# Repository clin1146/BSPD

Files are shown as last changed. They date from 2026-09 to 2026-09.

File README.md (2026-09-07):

# Brake System Plausibility Device (BSPD)

**Manchester Stinger Motorsports** · Rev V4.0

The BSPD is a **non-programmable safety circuit**, implemented entirely in discrete
logic with **no microcontroller anywhere in the fault-detection or shutdown path**.
It continuously monitors the throttle position sensor (TPS) and brake pressure
sensor (BPS) and cuts power to the vehicle if either reports an implausible
condition.

---

## Fault conditions

### 1. Simultaneous brake and throttle
If the BPS indicates the brakes are applied while the TPS reads **more than 25 %
above idle position**, and both conditions persist continuously for **500 ms**, the
circuit cuts power to the vehicle.

### 2. Sensor signal out of range
If either the TPS or BPS signal falls outside the expected **0.5 V – 4.5 V** range
for **500 ms** — indicating a wiring fault, sensor failure, or an open or short
circuit — the circuit cuts power.

---

## Reset behaviour

Once the fault condition is no longer true, a 10-second timer starts. If no fault
recurs within that 10-second window, power resets automatically. If a fault recurs
during the window, the timer restarts, so power stays cut until a full 10 seconds
passes with no fault present.

---

## Functional block diagram

![BSPD functional block diagram: the BPS and TPS sensor signals feed an AND stage
(simultaneous brake and throttle); its output is OR'd with the SCS signal, which
flags either sensor leaving the 0.5–4.5 V range. The combined fault passes through
a 500 ms RC delay that latches Power Off, and drives an inverter into a 555-based
10 s timer that restores Power On once the fault has been clear for the full
window.](docs/system-block-diagram.png)

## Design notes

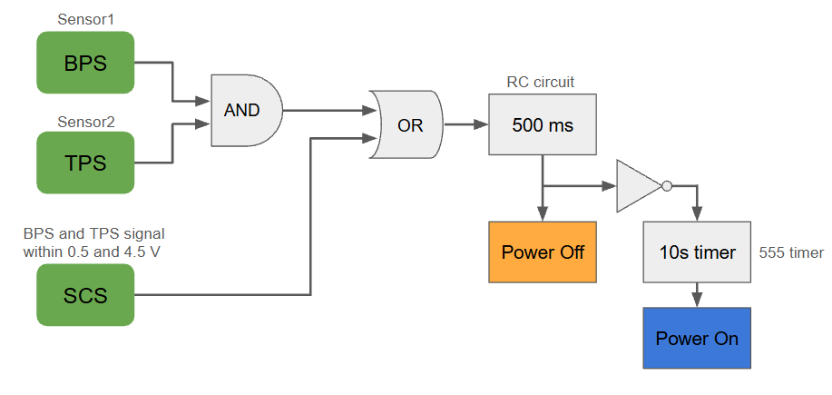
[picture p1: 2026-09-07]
docs/system-block-diagram.png

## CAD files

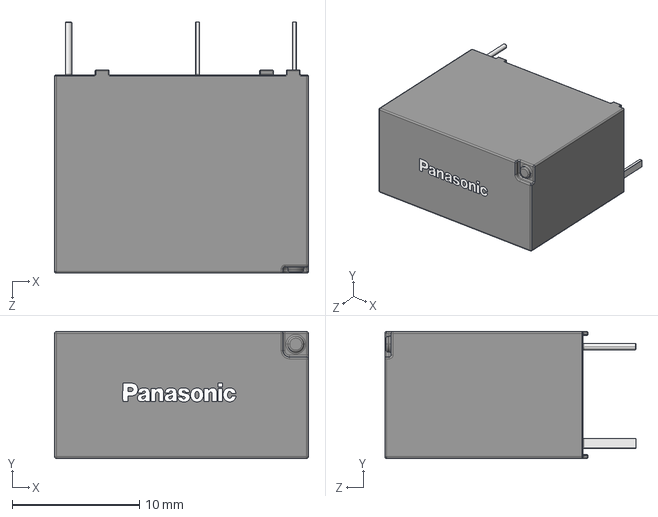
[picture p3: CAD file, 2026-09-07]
BSPD PCB/footprints/3D/ALQ3F12.stp
20.0 x 10.0 x 19.8 mm
ALQ305
Panasonic_Logo_5mm

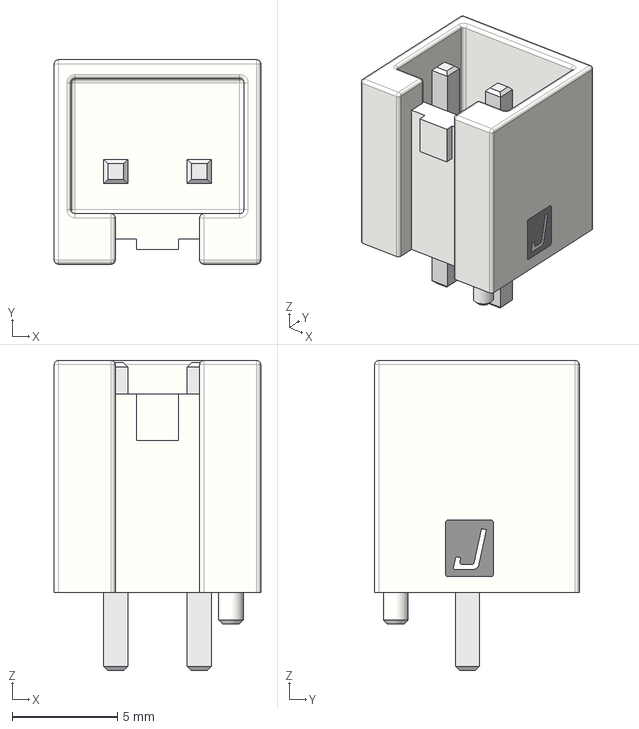
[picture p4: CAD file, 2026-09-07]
BSPD PCB/footprints/3D/B2P-VH-FB-B_LF__SN_.stp
9.80 x 9.70 x 14.7 mm

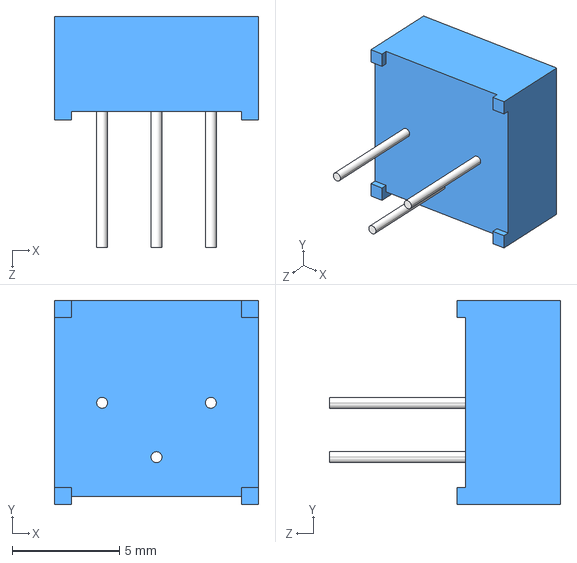
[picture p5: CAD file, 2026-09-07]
BSPD PCB/footprints/3D/3386P-1-500LF.stp
9.53 x 9.53 x 10.8 mm

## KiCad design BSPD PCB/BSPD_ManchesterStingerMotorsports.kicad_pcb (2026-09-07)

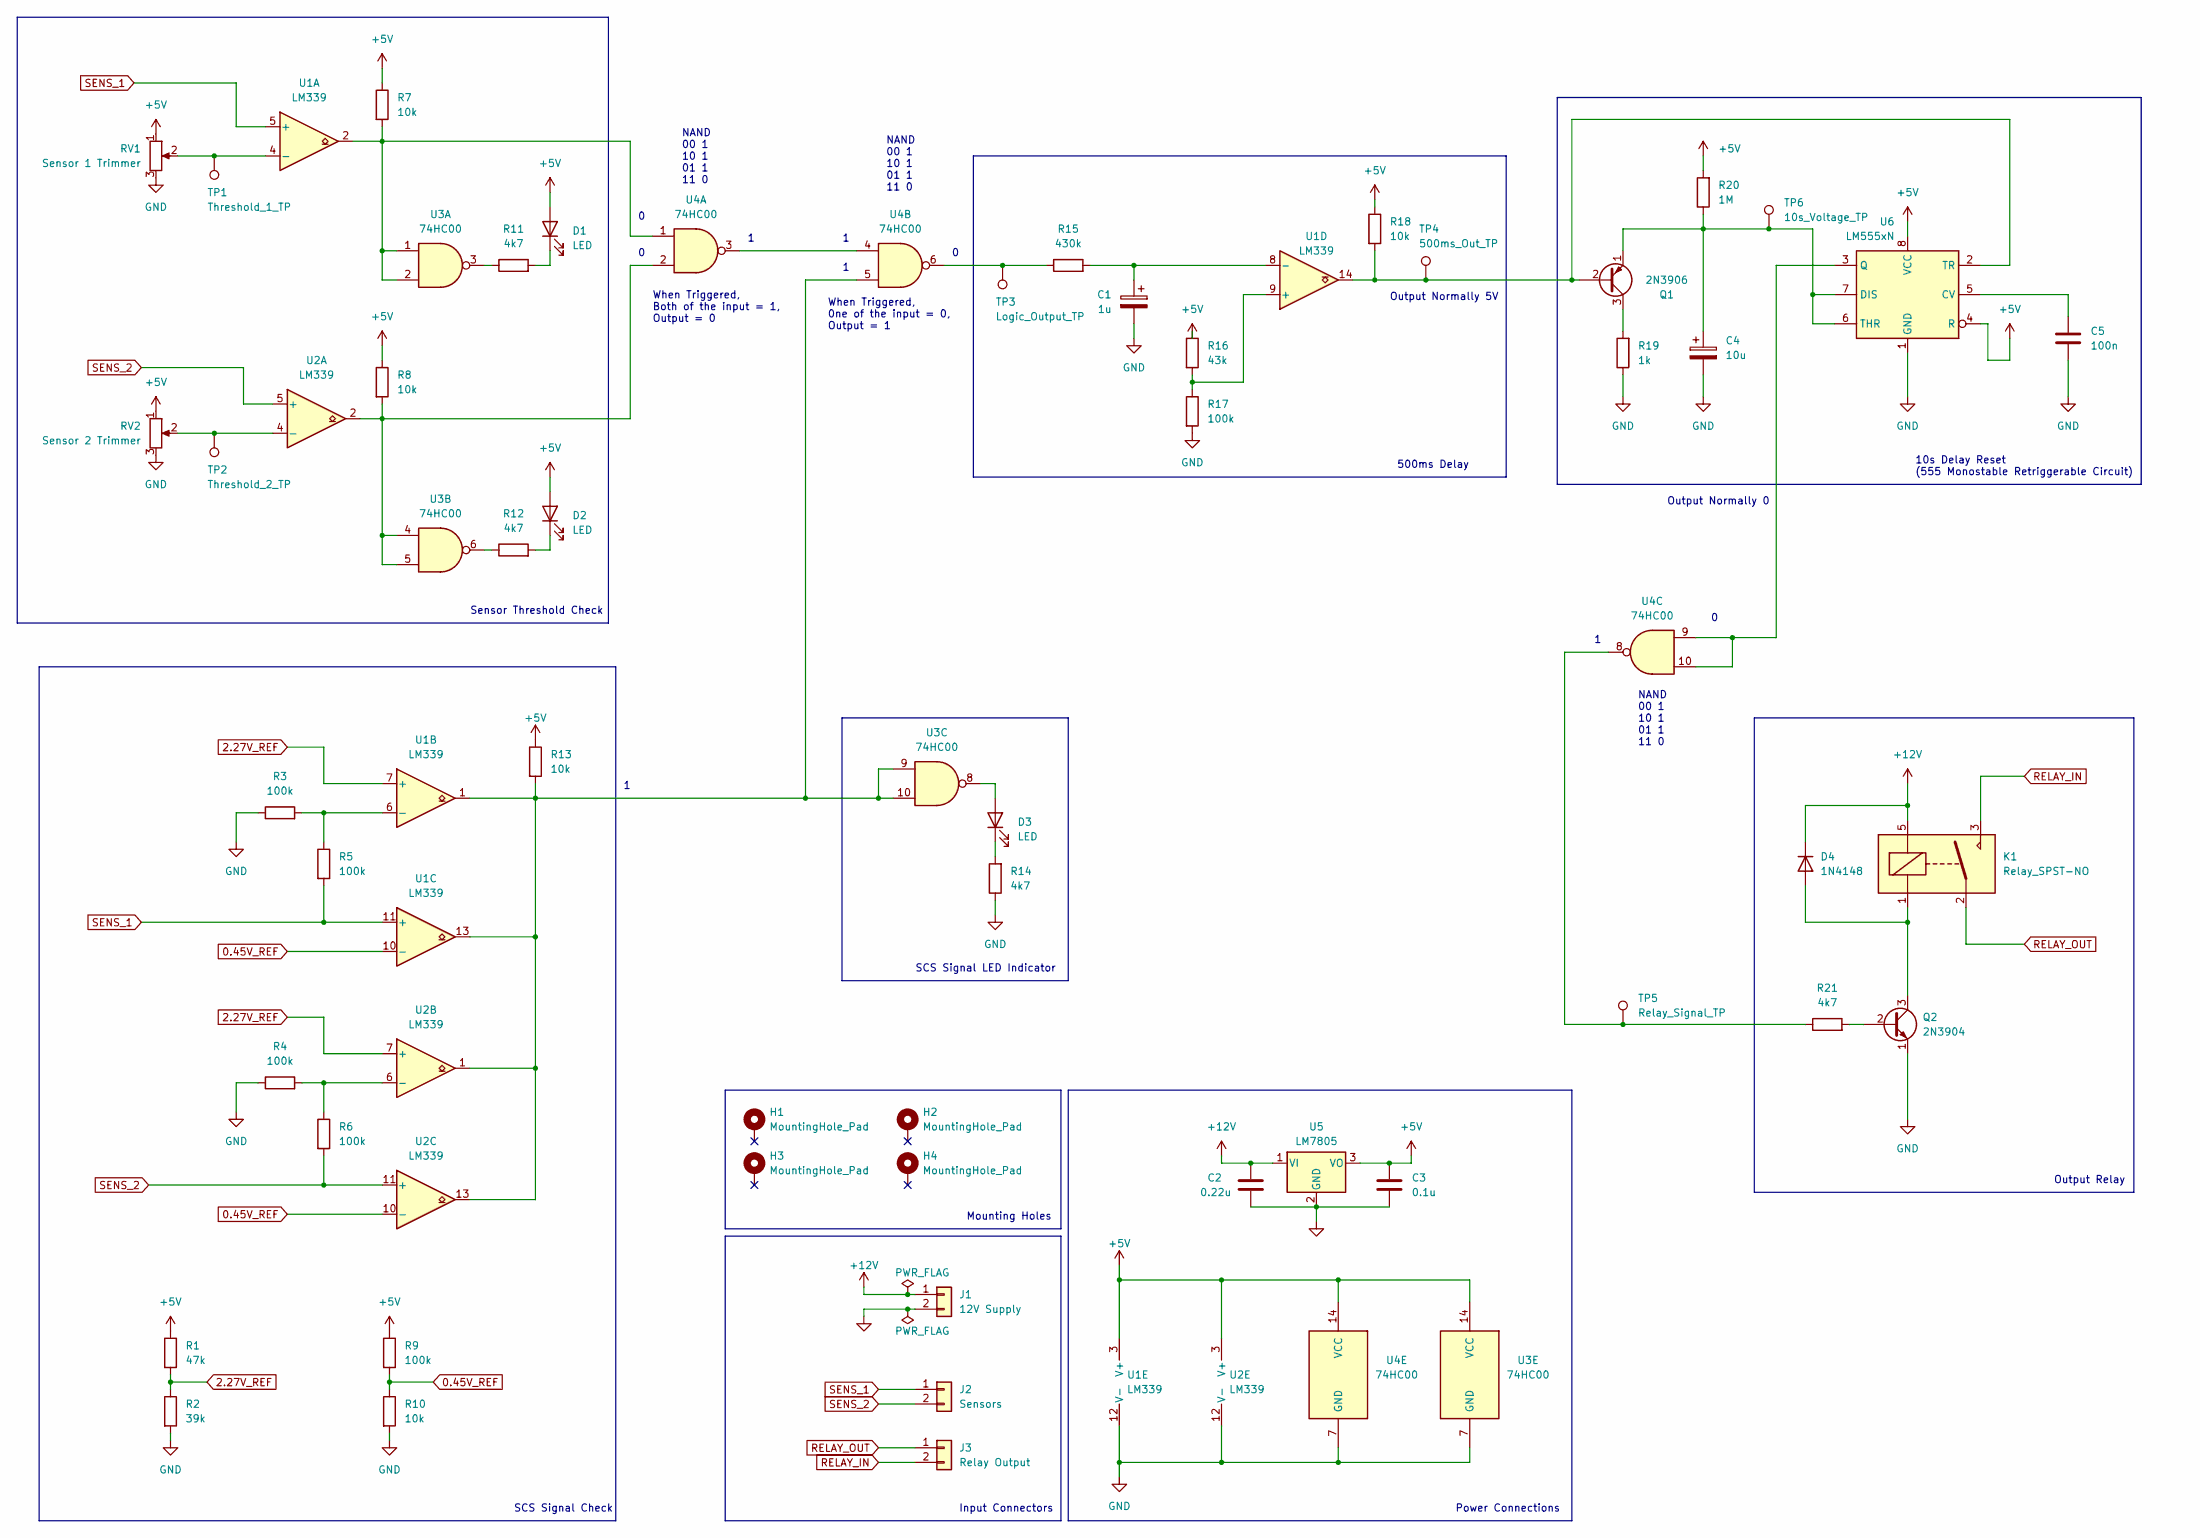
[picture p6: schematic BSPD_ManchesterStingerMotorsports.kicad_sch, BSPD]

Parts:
C1: 1u; CP_Radial_D5.0mm_P2.00mm
C2: 0.22u; C_Disc_D8.0mm_W2.5mm_P5.00mm
C3: 0.1u; C_Disc_D8.0mm_W2.5mm_P5.00mm
C4: 10u; CP_Radial_D5.0mm_P2.00mm
C5: 100n; C_Disc_D8.0mm_W2.5mm_P5.00mm
D1, D2, D3: LED; LED_D3.0mm
D4: 1N4148; D_DO-35_SOD27_P7.62mm_Horizontal
H1, H2, H3, H4: MountingHole_Pad; MountingHole_3.2mm_M3_DIN965_Pad
J1: 12V Supply; JST_VH_B2P-VH-FB-B_1x02_P3.96mm_Vertical
J2: Sensors; TerminalBlock_Phoenix_MPT-0,5-2-2.54_1x02_P2.54mm_Horizontal
J3: Relay Output; JST_VH_B2P-VH-FB-B_1x02_P3.96mm_Vertical
K1: Relay_SPST-NO; ALQ305
Q1: 2N3906; TO-92L_Wide
Q2: 2N3904; TO-92L_Wide
R1: 47k; R_Axial_DIN0207_L6.3mm_D2.5mm_P10.16mm_Horizontal
R2: 39k; R_Axial_DIN0207_L6.3mm_D2.5mm_P10.16mm_Horizontal
R3, R4, R5, R6, R9, R17: 100k; R_Axial_DIN0207_L6.3mm_D2.5mm_P10.16mm_Horizontal
R7, R8, R10, R13, R18: 10k; R_Axial_DIN0207_L6.3mm_D2.5mm_P10.16mm_Horizontal
R11, R12, R14, R21: 4k7; R_Axial_DIN0207_L6.3mm_D2.5mm_P10.16mm_Horizontal
R15: 430k; R_Axial_DIN0207_L6.3mm_D2.5mm_P10.16mm_Horizontal
R16: 43k; R_Axial_DIN0207_L6.3mm_D2.5mm_P10.16mm_Horizontal
R19: 1k; R_Axial_DIN0207_L6.3mm_D2.5mm_P10.16mm_Horizontal
R20: 1M; R_Axial_DIN0207_L6.3mm_D2.5mm_P10.16mm_Horizontal
RV1: Sensor 1 Trimmer; Potentiometer_Bourns_3386P_Vertical
RV2: Sensor 2 Trimmer; Potentiometer_Bourns_3386P_Vertical
TP1: Threshold_1_TP; TestPoint_Loop_D1.80mm_Drill1.0mm_Beaded
TP2: Threshold_2_TP; TestPoint_Loop_D1.80mm_Drill1.0mm_Beaded
TP3: Logic_Output_TP; TestPoint_Loop_D1.80mm_Drill1.0mm_Beaded
TP4: 500ms_Out_TP; TestPoint_Loop_D1.80mm_Drill1.0mm_Beaded
TP5: Relay_Signal_TP; TestPoint_Loop_D1.80mm_Drill1.0mm_Beaded
TP6: 10s_Voltage_TP; TestPoint_Loop_D1.80mm_Drill1.0mm_Beaded
U1, U2: LM339; DIP-14_W7.62mm
U3, U4: 74HC00; DIP-14_W7.62mm
U5: LM7805; TO-220-3_Horizontal_TabDown
U6: LM555xN; DIP-8_W7.62mm

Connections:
0.45V_REF: R9.2, R10.1, U1.10 (-), U2.10 (-)
2.27V_REF: R1.2, R2.1, U1.7 (+), U2.7 (+)
+5V: C3.1, D1.2 (A), D2.2 (A), R1.1, R7.1, R8.1, R9.1, R13.1, R16.1, R18.1, R20.2, RV1.1, RV2.1, U1.3 (V+), U2.3 (V+), U3.14 (VCC), U4.14 (VCC), U5.3 (VO), U6.4 (R), U6.8 (VCC)
+12V: C2.1, D4.1 (K), J1.1, K1.5, U5.1 (VI)
GND: C1.2, C2.2, C3.2, C4.2, C5.2, J1.2, Q2.1 (E), R2.2, R3.1, R4.1, R10.2, R14.1, R17.2, R19.1, RV1.3, RV2.3, U1.12 (V-), U2.12 (V-), U3.7 (GND), U4.7 (GND), U5.2 (GND), U6.1 (GND)
unnamed: D1.1 (K), R11.2
unnamed: D2.1 (K), R12.2
unnamed: D3.2 (A), U3.8
unnamed: D3.1 (K), R14.2
unnamed: D4.2 (A), K1.1, Q2.3 (C)
unnamed: Q1.2 (B), R18.2, TP4.1, U1.14, U6.2 (TR)
unnamed: Q1.3 (C), R19.2
unnamed: C4.1, Q1.1 (E), R20.1, TP6.1, U6.6 (THR), U6.7 (DIS)
unnamed: Q2.2 (B), R21.2
unnamed: R7.2, U1.2, U3.1, U3.2, U4.1
unnamed: R8.2, U2.2, U3.4, U3.5, U4.2
unnamed: R11.1, U3.3
unnamed: R12.1, U3.6
unnamed: R13.2, U1.1, U1.13, U2.1, U2.13, U3.9, U3.10, U4.5
unnamed: R15.1, TP3.1, U4.6
unnamed: R21.1, TP5.1, U4.8
unnamed: RV1.2, TP1.1, U1.4 (-)
unnamed: R3.2, R5.1, U1.6 (-)
unnamed: R16.2, R17.1, U1.9 (+)
unnamed: C1.1, R15.2, U1.8 (-)
unnamed: RV2.2, TP2.1, U2.4 (-)
unnamed: R4.2, R6.1, U2.6 (-)
unnamed: U4.3, U4.4
unnamed: C5.1, U6.5 (CV)
unnamed: U4.9, U4.10, U6.3 (Q)
RELAY_IN: J3.2, K1.3
RELAY_OUT: J3.1, K1.2
SENS_1: J2.1, R5.2, U1.5 (+), U1.11 (+)
SENS_2: J2.2, R6.2, U2.5 (+), U2.11 (+)

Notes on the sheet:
SCS Signal Check
When Triggered, Both of the input = 1, Output = 0
500ms Delay
Mounting Holes
Output Relay
SCS Signal LED Indicator
Power Connections
NAND 00 1 10 1 01 1 11 0
Sensor Threshold Check
Output Normally 5V
Input Connectors
When Triggered, 0ne of the input = 0, Output = 1
10s Delay Reset (555 Monostable Retriggerable Circuit)
Output Normally 0

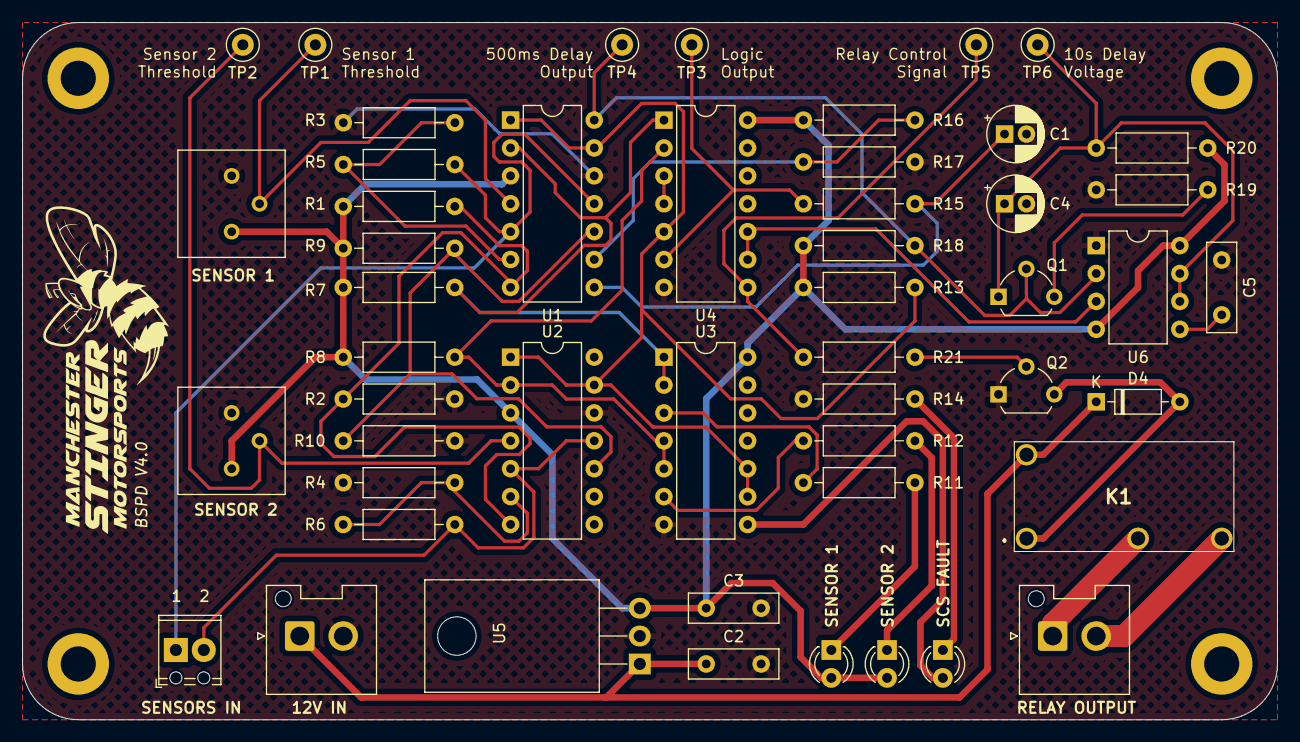
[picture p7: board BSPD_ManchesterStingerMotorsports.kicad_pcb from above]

Board: 2 copper layers, 114.3 x 63.5 mm, 54 parts (0 on the bottom side), 34 nets.
